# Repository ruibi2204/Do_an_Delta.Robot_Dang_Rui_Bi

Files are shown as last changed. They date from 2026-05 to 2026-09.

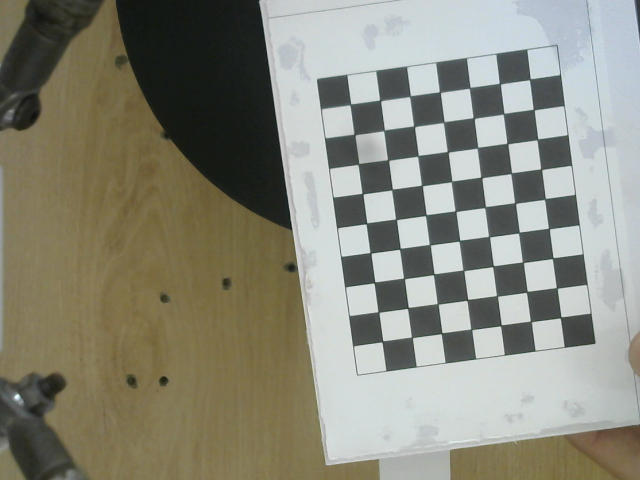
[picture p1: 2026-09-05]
Xử lý ảnh/Calibrarion_XY/images/calib_070.png

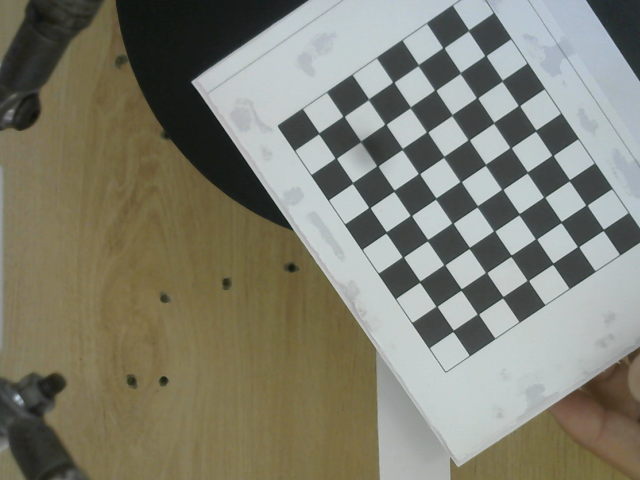
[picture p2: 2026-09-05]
Xử lý ảnh/Calibrarion_XY/images/calib_063.png

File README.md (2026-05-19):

ĐẶNG RUI BI_CƠ ĐIỆN TỬ
ĐỒ ÁN TỐT NGHIỆP: Thiết kế chế tạo robot song song delta phục vụ cho học tập và nghiên cứu
Chi tiết: + Xây dụng mô hình toán với cấu trúc song song
          + Xây dựng cấu trúc code chuẩn, logic
          + Tạo ra mô hình cơ khí hoàn chỉnh từ thiết kế đến gia công lắp ráp
          + Ứng dụng vào nhiều bài toán khác nhau mang tính đa dạng
          + Kết hợp thị giác máy tính làm đôi mắt cho các dạng bài toán xác định vật thể
          + Dùng bộ điều khiển PID giúp Robot di chuyển ổn định và hạ thấp sai số đến tối thiểu
Mã số SINH VIÊN: CNCD2211024
Trường Đại học Kỹ thuật - Công nghệ Cần Thơ

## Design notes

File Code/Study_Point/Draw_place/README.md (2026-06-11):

# Delta Robot Trajectory Controller

Phần mềm điều khiển quỹ đạo Robot Delta — Đồ án tốt nghiệp.

## Cấu trúc dự án

```
delta_robot/
├── main.py                          ← Chạy file này
├── kinematics/
│   ├── __init__.py
│   └── inverse_kinematics.py        ← Động học nghịch (Weierstrass)
├── trajectory/
│   ├── __init__.py
│   └── generator.py                 ← Sinh quỹ đạo tròn / vuông / tam giác
├── communication/
│   ├── __init__.py
│   └── uart_comm.py                 ← Giao tiếp Serial với stepper driver
└── gui/
    ├── __init__.py
    └── controller_gui.py            ← Giao diện Tkinter full-screen
```

## Thông số robot

| Tham số | Giá trị | Mô tả |
|---|---|---|
| R | 100 mm  | Bán kính mâm tĩnh |
| a | 130 mm  | Chiều dài cánh tay trên |
| b | 298 mm  | Chiều dài cánh tay dưới |
| r | 35.3 mm | Bán kính mâm động |
| u | 3.8 | Tỉ số truyền đai stepper |

## Cài đặt

```bash
pip install numpy pyserial
```

> `pyserial` là tùy chọn — nếu chưa cài, chương trình tự động dùng chế độ **DRY-RUN** (mô phỏng, không cần phần cứng).

## Chạy chương trình

```bash
cd delta_robot
python main.py
```

## Hướng dẫn sử dụng

1. **Chọn hình** (Tròn / Vuông / Tam giác) ở panel trái
2. **Nhập tham số** (bán kính, cạnh, tâm XY, độ cao Z)
3. **Kết nối Serial**: chọn cổng COM (hoặc để DRY-RUN để test)
4. Nhấn **▶ BẮT ĐẦU VẼ** — quan sát quỹ đạo trên canvas và góc khớp bên dưới
5. Nhấn **⌂ HOME** để đưa robot về vị trí gốc

## Định dạng UART

Mỗi bước gửi một dòng ASCII:

```
T1:<stepper1> T2:<stepper2> T3:<stepper3>\n
```

Trong đó `stepper_i = theta_i × 3.8` (tỉ số truyền đai).

**Ví dụ:**
```
T1:42.56 T2:-31.08 T3:38.95
HOME
```

## Mở rộng

- Thêm hình vẽ mới: tạo hàm trong `trajectory/generator.py` và thêm tab trong `gui/controller_gui.py`
- Thay đổi giao thức UART: chỉnh hàm `send_angles()` trong `communication/uart_comm.py`
- Thay đổi thông số robot: chỉnh hằng số trong `kinematics/inverse_kinematics.py`

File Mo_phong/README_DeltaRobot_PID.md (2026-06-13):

# ROBOT DELTA – BỘ ĐIỀU KHIỂN PID SIMULINK

## Cấu trúc file

| File | Chức năng |
|---|---|
| `delta_robot_pid.m` | Script chính: mô phỏng PID + tự tạo model Simulink |
| `build_delta_simulink.m` | Hàm riêng: chỉ tạo file `.slx` (dùng API Simulink) |

---

## Cách sử dụng

### Cách 1 – Chạy nhanh (không cần Simulink license)
```matlab
run('delta_robot_pid.m')
```
- Mô phỏng bằng vòng lặp MATLAB (RK4)
- Vẽ 9 đồ thị: góc, sai số, mô-men
- Tính RMSE từng khớp
- Tự động gọi `create_simulink_model()` để sinh file `.slx`

### Cách 2 – Chỉ tạo Simulink model
```matlab
build_delta_simulink()
```
Yêu cầu: **MATLAB R2019b+** có Simulink.

---

## Sơ đồ khối Simulink (mỗi khớp)

```
Ref_Ji ──┬──► [Sum] ──► [PID Controller] ──► [Plant 1/(Js+b)] ──► [Integrator] ──► θi
         │      ▲─────────────────────────────────────────────────────────────────────┘
         │    (phản hồi âm)
         └── [Scope / To Workspace]
```

**3 vòng điều khiển độc lập** – một vòng cho mỗi khớp (θ₁, θ₂, θ₃).

---

## Thông số mặc định

### Cơ học robot Delta
| Ký hiệu | Giá trị | Đơn vị |
|---|---|---|
| L1 (cánh tay trên) | 0.30 | m |
| L2 (cánh tay dưới) | 0.60 | m |
| r_base | 0.20 | m |
| r_platform | 0.05 | m |
| m (tải) | 0.50 | kg |
| J (quán tính khớp) | 0.01 | kg.m² |
| b (cản) | 0.05 | N.m.s/rad |

### Tham số PID (3 khớp giống nhau)
| Tham số | Giá trị |
|---|---|
| Kp | 120 |
| Ki | 15 |
| Kd | 8 |
| τ_max | ±30 N.m |
| Anti-windup | Clamping |

### Quỹ đạo tham chiếu (hình sin lệch pha 120°)
```
θ1_ref(t) = 0.5·sin(π·t)
θ2_ref(t) = 0.5·sin(π·t + 2π/3)
θ3_ref(t) = 0.5·sin(π·t + 4π/3)
```

---

## Điều chỉnh PID

Thay đổi giá trị trong phần **Section 2** của `delta_robot_pid.m`:
```matlab
pid.Kp1 = 120;   pid.Ki1 = 15;   pid.Kd1 = 8;
```

**Hướng dẫn chỉnh thô:**
- Tăng `Kp` → đáp ứng nhanh hơn, dễ vọt lố
- Tăng `Ki` → giảm sai số tĩnh, dễ dao động
- Tăng `Kd` → giảm vọt lố, tăng ổn định

---

## Yêu cầu
- MATLAB R2019b trở lên
- Simulink (để chạy `build_delta_simulink.m`)
- Control System Toolbox (tùy chọn)

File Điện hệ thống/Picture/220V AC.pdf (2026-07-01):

## 220 VAC

L | N | E_STOP

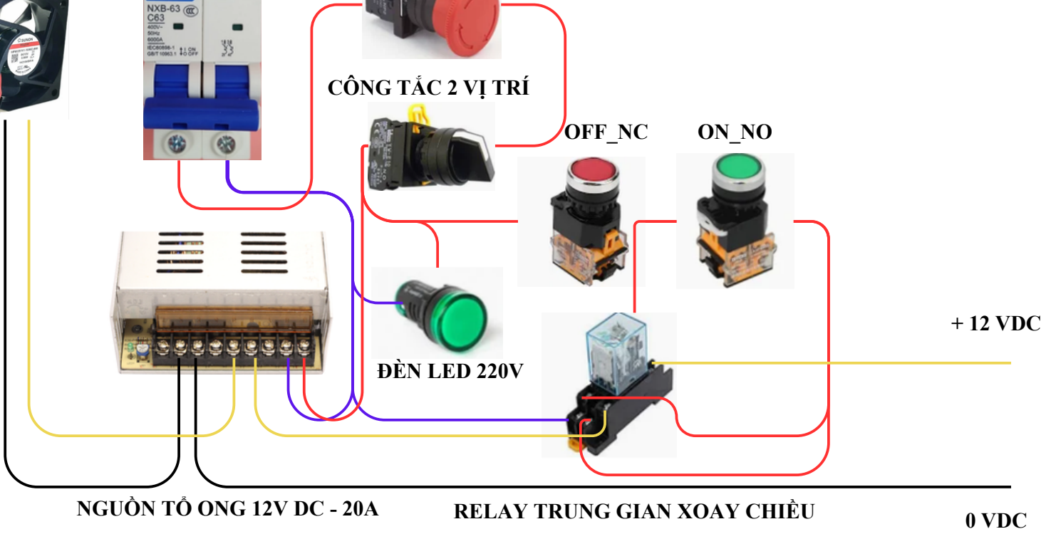
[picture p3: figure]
ĐÈN LED 220V; CÔNG TẮC 2 VỊ TRÍ; OFF_NC; + 12 VDC; 0 VDC

NGUỒN TỔ ONG 12V DC - 20A | RELAY TRUNG GIAN XOAY CHIỀU

QUẠT TẢN NHIỆT

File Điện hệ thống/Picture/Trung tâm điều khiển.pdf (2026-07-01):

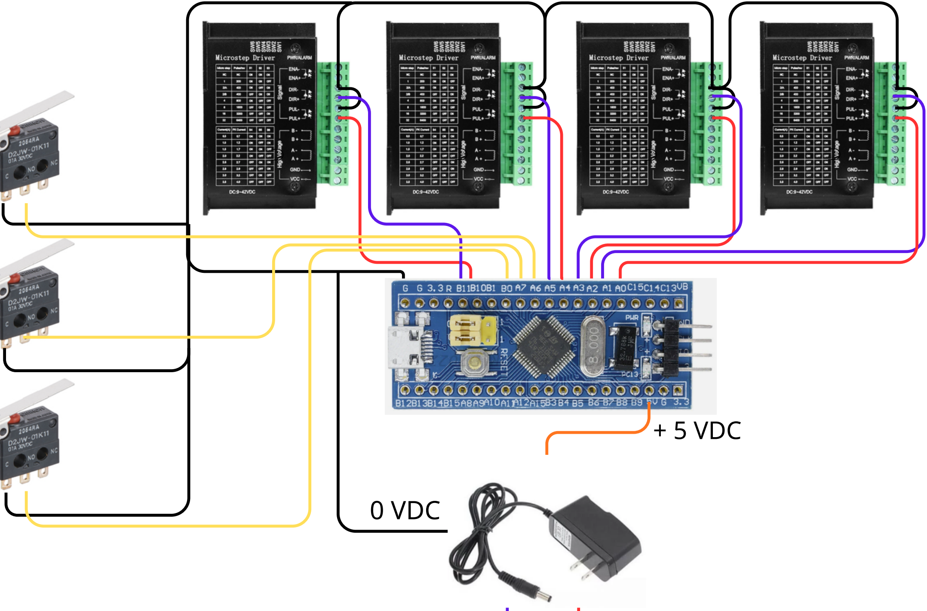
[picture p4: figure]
0 VDC; + 5 VDC

N L
220V AC

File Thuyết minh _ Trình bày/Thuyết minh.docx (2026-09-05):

TRƯỜNG ĐẠI HỌC KỸ THUẬT - CÔNG NGHỆ CẦN THƠ

KHOA KỸ THUẬT CƠ KHÍ

ĐỒ ÁN TỐT NGHIỆP

Đề tài:

THIẾT KẾ, CHẾ TẠO ROBOT SONG SONG DELTA

ỨNG DỤNG TRONG HỌC TẬP VÀ NGHIÊN CỨU

GIẢNG VIÊN HƯỚNG DẪN | SINH VIÊN THỰC HIỆN
Th.S. Trần Sĩ Lâm | Họ và tên: Đặng Rui Bi MSSV: CNCD2211024 Ngành: Công nghệ - Kỹ thuật Cơ Điện Tử

Cần thơ, tháng … năm 2026

TRƯỜNG ĐẠI HỌC KỸ THUẬT- CÔNG NGHỆ CẦN THƠ

KHOA KỸ THUẬT CƠ KHÍ

ĐỒ ÁN TỐT NGHIỆP

Đề tài:

THIẾT KẾ, CHẾ TẠO ROBOT SONG SONG DELTA

ỨNG DỤNG TRONG HỌC TẬP VÀ NGHIÊN CỨU

GIẢNG VIÊN HƯỚNG DẪN | SINH VIÊN THỰC HIỆN
Th.S. Trần Sĩ Lâm | Họ và tên: Đặng Rui Bi MSSV: CNCD2211024 Ngành: Công nghệ - Kỹ thuật Cơ Điện Tử

Cần thơ, tháng … năm 202

# LỜI CAM ĐOAN

Tôi tên là Đặng Rui Bi (mã số sinh viên: CNCD2211024), là sinh viên ngành Công nghệ - Kỹ thuật Cơ điện tử, khóa 2022. Tôi xin cam đoan đồ án này là công trình nghiên cứu khoa học thực sự của tôi và được sự hướng dẫn của ThS. Trần Sĩ Lâm.

Các thông tin được sử dụng tham khảo trong đề tài được thu thập từ các nguồn đáng tin cậy, đã được kiểm chứng, được công bố rộng rãi và được chúng tôi trích dẫn nguồn gốc rõ ràng ở danh mục Tài liệu tham khảo. Các kết quả nghiên cứu được trình bày trong đồ án này là do chính tôi thực hiện một cách nghiêm túc, trung thực và không trùng lặp với các đề tài khác đã được công bố trước đây.

Tôi xin lấy danh dự và uy tín của bản thân để đảm bảo cho lời cam đoan này.

Cần Thơ, ngày … tháng … năm 2026

Giảng viên hướng dẫn | Tác giả thực hiện
Trần Sĩ Lâm | Đặng Rui Bi

# LỜI CẢM ƠN

Lời đầu tiên, em xin gửi lời cảm ơn chân thành nhất đến các quý thầy cô Khoa Kỹ thuật Cơ khí – những người đã truyền đạt kiến thức, giúp đỡ và tạo điều kiện thuận lợi cho chúng em trong suốt quá trình học tập và rèn luyện tại trường.

Đặc biệt, em xin bày tỏ lòng biết ơn sâu sắc đến ThS. Trần Sĩ Lâm, giảng viên đã trực tiếp hướng dẫn và đồng hành cùng em xuyên suốt quá trình thực hiện đồ án này. Sự kiên nhẫn, tận tâm và những chỉ dẫn chuyên môn quý báu của Thầy là nguồn động lực lớn lao giúp em vượt qua những khó khăn, thách thức trong quá trình nghiên cứu kỹ thuật. Những kiến thức và kinh nghiệm thực tiễn mà Thầy chia sẻ không chỉ giúp nhóm hoàn thiện đồ án một cách tốt nhất mà còn giúp em nhìn nhận ra những thiếu sót để cải thiện và phát triển bản thân hơn nữa.

Dù đã dành nhiều tâm huyết và nỗ lực, nhưng do kiến thức còn hạn chế, đồ án chắc chắn không tránh khỏi những khiếm khuyết. Nhóm chúng em rất mong nhận được những ý kiến đóng góp của các thầy cô để đề tài được hoàn thiện hơn.

Một lần nữa, em xin chân thành cảm ơn Thầy!

Cần Thơ, ngày … tháng … năm 2026

Tác giả thực hiện

Đặng Rui Bi

# NHẬN XÉT CỦA GIẢNG VIÊN

# MỤC LỤC

# DANH MỤC HÌNH

# DANH MỤC BẢNG

# DANH MỤC TỪ VIẾT TẮT

# DANH MỤC KÝ HIỆU

# LỜI MỞ ĐẦU

Trong thời kỳ phát triển công nghiệp hiện nay, ngành công nghiệp robot đóng vai trò vô cùng quan trọng, trở thành động lực phát triển của nhiều lĩnh vực sản xuất, y tế, dịch vụ,… Robot không những giúp tự động hóa các quy trình, nâng cao năng suất mà còn giảm thiểu rủi ro cho con người trong các môi trường nguy hiểm.

Trong số các loại robot công nghiệp, robot song song nổi bật với những ưu điểm vượt trội về độ cứng vững cao, độ chính xác và tốc độ làm việc nhanh chóng. Đặc biệt, robot Delta, với cấu trúc động học song song độc đáo, đã chứng minh được hiệu quả vượt trội trong các ứng dụng đòi hỏi tốc độ cao như phân loại, đóng gói, lắp ráp linh kiện điện tử và phẫu thuật. Khả năng di chuyển nhanh và chính xác của robot Delta đã mở ra nhiều tiềm năng ứng dụng mới, góp phần nâng cao hiệu suất và tối ưu hóa quy trình sản xuất.

Với mong muốn tìm hiểu sâu hơn về lĩnh vực robot học nói chung và robot song song Delta nói riêng, cũng như ứng dụng những kiến thức đã học vào thực tiễn, tôi đã lựa chọn đề tài "Thiết kế, chế tạo robot song song Delta phục vụ cho học tập và nghiên cứu" làm đề tài báo cáo tốt nghiệp của mình. Đề tài này không chỉ giúp tôi củng cố kiến thức về động học, động lực học và điều khiển robot, mà còn trang bị những kỹ năng thực tế trong việc xây dựng và vận hành một hệ thống robot hoàn chỉnh.

Tuy nhiên, với phạm vi kiến thức còn hạn chế, trong quá trình thực hiện đề tài không tránh khỏi những thiếu sót và gặp phải nhiều thách thức. Tôi rất mong nhận được sự quan tâm, góp ý và hỗ trợ từ quý thầy cô để có thể hoàn thiện tốt đề tài này.

Em xin chân thành cảm ơn!

# TÓM TẮT

Trong thời đại tự động hóa trong công nghiệp ngày càng phát triển mạnh mẽ, các Robot tự hành trong các dây chuyền sản xuất ngày càng phổ biến trong đó có Robot song song Delta. Tôi quyết định thực hiện đề tài Thiết kế, chế tạo Robot song song Delta nhằm tạo ra mô hình Robot Delta hoàn chỉnh với mục tiêu tối ưu hóa khả năng điều khiển vị trí và quy hoạch quỹ đạo chính xác trong không gian ba chiều. Nội dung nghiên cứu bắt đầu từ việc thiết lập nền tảng lý thuyết thông qua mô hình toán học động học thuận và nghịch bằng phương pháp giải tích, giúp xác định chính xác không gian làm việc và làm cơ sở cho việc tính toán động lực học để lựa chọn hệ thống truyền động phù hợp. Song song đó, hệ thống cơ khí được thiết kế tối ưu với kết cấu nhẹ nhằm giảm thiểu quán tính, kết hợp cùng bộ điều khiển trung tâm được thiết lập linh động và giao diện giao tiếp trực tiếp trên laptop để giám sát vận hành thời gian thực. Đặc biệt, đề tài đi sâu vào việc tích hợp hệ thống thị giác máy tính hiện đại để nhận diện, phân loại vật thể theo màu sắc và hình dạng, đồng thời triển khai các thuật toán điều khiển giúp robot thực hiện mượt mà các quỹ đạo hình học phức tạp như hình tròn, hình vuông và hình tam giác. Kết quả cuối cùng hướng tới việc tạo ra một hệ thống Robot Delta hoàn chỉnh, vận hành ổn định và có tính tùy biến cao, đóng vai trò như một học cụ nghiên cứu thực thụ.

# CHƯƠNG 1 TỔNG QUAN VỀ ĐỀ TÀI

# 1.1 Giới thiệu về Robot công nghiệp

Robot công nghiệp thường được đề cập trong bối cảnh các đổi mới công nghệ của thế kỷ 21. Tuy nhiên, nguồn gốc của chúng đã xuất hiện từ rất sớm - vào những năm 1950.

Hình 1.1 Robot "Unimate" – robot công nghiệp đầu tiên trên dây chuyền lắp ráp ô tô

Robot công nghiệp lần đầu tiên được thương mại hóa vào đầu thập niên 1960, chủ yếu phục vụ trong các dây chuyền lắp ráp ô tô. Những thiết bị đầu tiên được thiết kế với cánh tay thủy lực hoặc khí nén, chủ yếu để nâng vật nặng và hỗ trợ các công việc nguy hiểm. Đến giữa những năm 1980, robot được nhìn nhận là “cỗ máy của tương lai”. Đây là giai đoạn quan trọng, đánh dấu sự chuyển đổi từ máy cơ học sang robot có khả năng cảm nhận. Robot bắt đầu được tích hợp cảm biến lực, cảm biến vị trí, thị giác máy (machine vision) dù còn sơ khai nhưng đã mở ra hướng phát triển mới cho khả năng tương tác với môi trường.

Bên cạnh đó, sự phát triển của phần cứng máy tính, đặc biệt là việc giảm giá thành bộ vi xử lý, đã cho phép các robot được điều khiển linh hoạt hơn, thông minh hơn và phù hợp với nhiều quy trình sản xuất khác nhau. Trong bối cảnh đó, các loại robot có cấu trúc đặc biệt như robot song song delta cũng bắt đầu được chú ý nhờ khả năng hoạt động cực nhanh và chính xác, phù hợp với các nhiệm vụ như phân loại sản phẩm trên băng chuyền.

Hiện nay, Robot được coi là một phần không thể thiếu trong công nghiệp, tồn tại với qui mô vượt trội và ngày càng thông minh. Có rất nhiều loại Robot ngày càng được cải tiến mạnh mẽ cùng với đó là khả năng xử lý vượt trội, phổ biến có thể kể đến như:

- Robot nối tiếp:

Robot nối tiếp là một hệ động học hở bao gồm nhiều khâu nối tiếp với nhau thông qua các khớp, thường là khớp tịnh tiến hoặc khớp xoay. Các khớp cho phép các khâu chuyển động tương đối với nhau, từ đó robot có thể thực hiện nhiều tác vụ từ việc điều khiển cơ cấu tác động di chuyển trong không gian.

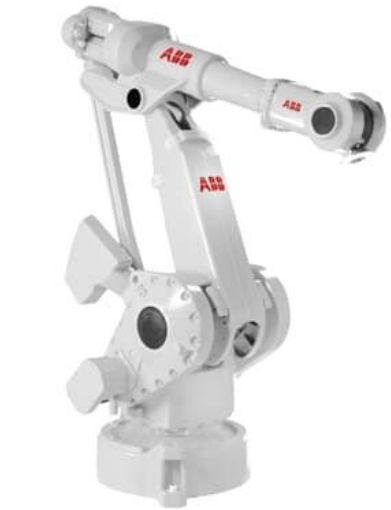
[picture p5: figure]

Với kết cấu nối tiếp, robot có vùng không gian làm việc lớn hơn so với kích thước của nó. Nhờ đó robot nối tiếp được ứng dụng nhiều trong sản xuất ô tô, sắp xếp các pallet, sơn phủ, hàn, cắt vật liệu và nhiều ngành khác. Tuy vậy robot nối tiếp cũng có một số nhược điểm như robot nối tiếp thường có khối lượng lớn nên quán tính lớn do đó robot bị giới hạn về mặt tốc độ chuyển động, tốc độ làm việc chưa cao.

Hình 1.2 Cánh tay Robot nối tiếp của tập đoàn ABB

- Robot song song:

Khác với robot nối tiếp, robot song song là là một hệ cơ cấu động học kín. Bộ phận công tác của robot được kết nối với khâu cố định thông qua chuỗi các khâu riêng biệt, trong đó bao gồm một khâu chủ động liên kết với khâu đế và khâu bị động liên kết với đầu công tác như hình 1.3. Chuyển động của bộ phận công tác được điều khiển thông qua việc điều khiển các chuỗi liên kết một cách phối hợp.

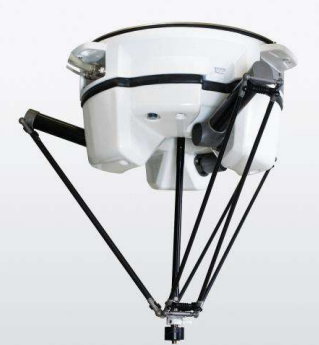
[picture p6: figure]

Hình 1.3 Robot IRB 360 - 3/1130 của tập đoàn ABB

Mặc dù robot song song có cấu trúc động học phức tạp, không gian làm việc nhỏ, khó thiết kế và điều khiển, nhưng nó có một số ưu điểm nổi trội so với robot nối tiếp. Các robot song song thường có khối lượng nhẹ nên có khả năng di chuyển với tốc độ cao, bên cạnh đó kết cấu song song giúp robot không bị tích lũy sai số như robot nối tiếp do các chuỗi liên kết ràng buộc lẫn nhau. Robot song song thường được sử dụng trong các ứng dụng có độ chính xác và tốc độ cao như ngành sản xuất, hàng không vũ trụ và y tế.

# 1.2 Giới thiệu Robot song song Delta

Robot Delta là một loại robot song song được phát minh bởi giáo sư Reymond Clavel và các cộng sự của ông vào năm 1986. Giống như các robot song song khác, robot Delta cũng có cấu trúc vòng kín được thể hiện ở hình 1.4. Trong đó có ba chuỗi động học độc lập, mỗi chuỗi gồm một đầu gắn với khâu giá cố định, đầu kia gắn với khâu công tác thông qua cơ cấu hình bình hành. Chuyển động của khâu công tác được điều khiển nhờ ba động cơ gắn trên giá cố định. Với cơ cấu đó, khâu công tác chỉ có thể chuyển động tịnh tiến theo các phương X, Y, Z trong không gian mà không xoay theo các phương này.

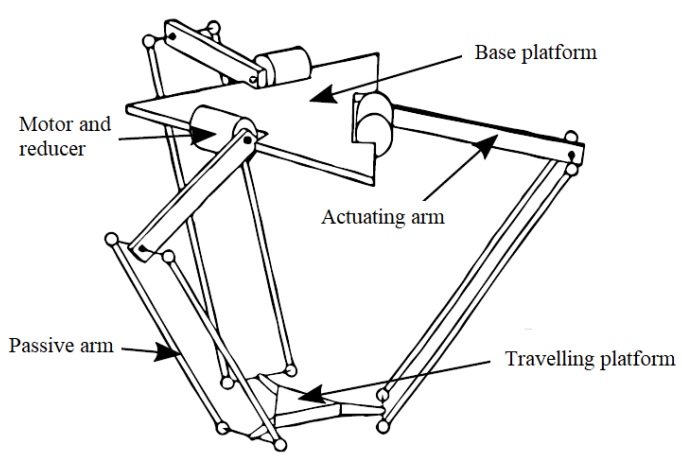
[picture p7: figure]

Hình 1.4 Kết cấu Delta Robot

Vì các bộ truyền động thường được đặt cố định trên khâu giá nên các khâu còn lại của robot thường được làm bằng các vật liệu rất nhẹ. Do đó, robot Delta thường có quán tính nhỏ, vì thế mà chúng có thể hoạt động ở tốc độ cao và có khả năng tăng tốc nhanh. Với những ưu điểm trên, robot Delta rất thích hợp để ứng dụng trong định vị và định hướng các sản phẩm trong các dây chuyền công nghiệp.

Đặc điểm nổi bật của Robot Delta:

- Tốc độ cực cao: Đây là ưu điểm nổi bật nhất của robot Delta. Do các động cơ được đặt cố định trên bệ tĩnh và chỉ các khâu nhẹ di chuyển, robot có thể đạt được gia tốc và tốc độ rất lớn, lên đến hàng trăm lần chọn và đặt mỗi phút.
- Độ chính xác và lặp lại cao: Cấu trúc song song giúp phân bố lực đều, giảm thiểu sai số tích lũy và độ võng, mang lại độ chính xác vị trí và độ lặp lại vượt trội (thường dưới 0.1mm).
- Vùng làm việc hình bán cầu: Vùng làm việc của robot Delta thường có hình dạng bán cầu hoặc tương tự, phù hợp cho các nhiệm vụ trong không gian giới hạn phía dưới nó.
- Chỉ có khả năng tịnh tiến (X, Y, Z) cơ bản: Robot Delta nguyên bản chỉ thực hiện được 3 bậc tự do tịnh tiến. Để có thêm khả năng quay (orientation), cần bổ sung thêm các khớp phụ hoặc cấu trúc phức tạp hơn (ví dụ: Delta 4 bậc tự do với trục quay ở cuối).
- Động học ngược đơn giản, động học thuận phức tạp: Việc tính toán động học ngược (từ vị trí mong muốn của bệ động để tìm ra góc quay của các động cơ) thường đơn giản và có thể giải được bằng phương pháp giải tích. Ngược lại, động học thuận (từ góc quay 10 của các động cơ để tìm ra vị trí của bệ động) thường phức tạp hơn và có thể cần giải bằng phương pháp số.
- Thiết kế vệ sinh (Hygienic Design): Do các động cơ và phần lớn cơ cấu truyền động nằm phía trên bệ tĩnh, robot Delta dễ dàng được thiết kế để đáp ứng các tiêu chuẩn vệ sinh nghiêm ngặt, lý tưởng cho ngành thực phẩm và dược phẩm.

# 1.3 Ứng dụng của Robot Delta

# 1.3.1 Trong lĩnh vực công nghệ cao, tự động hóa

Ứng dụng: Robot Delta là lựa chọn hàng đầu cho các ngành công nghiệp đòi hỏi tốc độ và độ chính xác cao trong việc xử lý các vật thể nhỏ và nhẹ:

- Phân loại và đóng gói: Trong ngành thực phẩm (kẹo, bánh quy), dược phẩm (viên thuốc), điện tử (linh kiện nhỏ).
- Lắp ráp linh kiện điện tử: Lắp ráp các chi tiết nhỏ, ví dụ như chip lên bảng mạch.
- Chọn và đặt (Pick-and-place): Di chuyển nhanh các vật thể từ vị trí này sang vị trí khác trên dây chuyền sản xuất.
- Kiểm tra sản phẩm: Di chuyển cảm biến hoặc camera để kiểm tra sản phẩm trên dây chuyền với tốc độ cao.
- Ứng dụng y tế: Một số biến thể được dùng trong phẫu thuật hoặc các thiết bị y tế đòi hỏi độ chính xác cao.

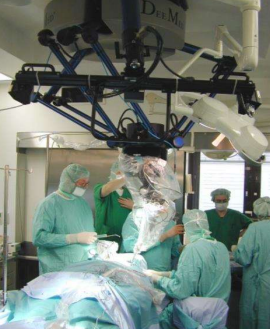
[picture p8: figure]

Hình 1.5 Ứng dụng Delta Robot trong đóng gói sản phẩm

Hình 1.6 Mang kính hiển vi phẫu thuật

# 1.3.2 Trong lĩnh vực học tập và nghiên cứu

Robot Delta là một đối tượng nghiên cứu điển hình trong lĩnh vực cơ học nhờ cấu trúc động học song song (parallel kinematics) độc đáo. Khác với các robot dạng chuỗi hở thông thường, Robot Delta sử dụng ba cánh tay cơ học được nối từ một đế cố định đến một mâm chuyển động (end-effector). Trong nghiên cứu, việc phân tích bài toán động học thuận và nghịch của Delta đòi hỏi các mô hình toán học phức tạp để xác định vị trí chính xác của mâm động dựa trên góc quay của các động cơ servo, stepper. Các nhà nghiên cứu thường tập trung vào việc tối ưu hóa "vùng làm việc" (workspace) và phân tích các điểm kỳ dị (singularities) để đảm bảo robot vận hành ổn định. Nhờ cấu tạo nhẹ và độ cứng vững cao, đây là mô hình lý tưởng để thử nghiệm các thiết kế cơ khí chính xác, nơi mà sai số tích lũy từ các khớp nối được giảm thiểu tối đa so với robot truyền thống.

Trong môi trường học thuật, robot Delta đóng vai trò là nền tảng quan trọng để triển khai và kiểm chứng các thuật toán điều khiển tốc độ cao. Do đặc thù được thiết kế cho các tác vụ "Pick and Place" (gắp và đặt), việc lập trình quỹ đạo (trajectory planning) cho Delta yêu cầu khả năng xử lý thời gian thực cực kỳ nhạy bén để đạt được gia tốc lớn mà không gây rung lắc. Sinh viên và nghiên cứu sinh thường ứng dụng các bộ điều khiển PID nâng cao, điều khiển mờ (Fuzzy Logic) hoặc mạng nơ-ron để tối ưu hóa chuyển động. Bên cạnh đó, việc tích hợp hệ thống thị giác máy tính (Computer Vision) vào robot Delta là một hướng nghiên cứu phổ biến, cho phép robot nhận diện, phân loại và bám sát đối tượng trong không gian ba chiều với độ trễ thấp. Đây chính là bước đệm quan trọng để phát triển các hệ thống sản xuất thông minh và tự động hóa linh hoạt trong tương lai.

# 1.3.3 Xét trên phạm vi Trường Đại học Kỹ thuật – Công nghệ Cần Thơ

Tại Trường Đại học Kỹ thuật – Công nghệ Cần Thơ, robot Delta không còn là một khái niệm quá xa lạ khi đã có những công trình nghiên cứu và sản phẩm thực nghiệm từ các thế hệ sinh viên đi trước. Tuy nhiên, phần lớn các nghiên cứu này thường tập trung vào những mục tiêu chuyên biệt, khiến việc tiếp cận hệ thống dưới dạng một nền tảng mở cho nhiều bài toán khác nhau vẫn còn gặp nhiều hạn chế, số bậc tự do là 3 bậc. Đây chính là động lực cốt lõi để tôi thực hiện đồ án này, với mong muốn xây dựng một mô hình robot Delta có tính linh hoạt cao và khả năng tùy biến linh hoạt hơn. Thay vì chỉ dừng lại ở một ứng dụng đơn lẻ, mục tiêu của tôi là tạo ra một cấu trúc có tính kế thừa, giúp các sinh viên khóa sau dễ dàng tiếp cận, thực hiện các bài toán từ điều khiển quỹ đạo phức tạp đến tích hợp thị giác máy tính. Việc tối ưu hóa cấu hình thiết bị không chỉ nhằm mục đích hoàn thành một đồ án tốt nghiệp, mà còn hướng đến việc xây dựng một học cụ nghiên cứu thực thụ, góp phần mở rộng không gian sáng tạo và ứng dụng công nghệ robot song song tại chính ngôi trường mình đang theo học.

# 1.4 Mục tiêu đặt ra và mục đích chính của đề tài

# 1.4.1 Mục tiêu

Với thực trạng cách thức điều khiển tại Trường Đại học Kỹ thuật - Công nghệ Cần Thơ còn khá đơn điệu, tôi quyết định xây dựng đề tài này với các mục tiêu cấp thiết như sau:

- Vận dụng các kiến thức đã tích góp trong suốt quá trình học tập tại trường.
- Xây dựng được mô hình toán, phân tích động học bao gồm thuận và nghịch của Robot.
- Chế tạo mô hình Robot Delta 4 bậc tự do.
- Tạo ra được mô hình hoàn thiện được kết hợp đầy đủ các kiến thức từ xử lý ảnh, thiết kế, mô phỏng đến lắp ráp cơ khí hoàn chỉnh.
- Thiết lập thuật toán và môi trường điều khiển linh động với các yêu cầu điều khiển khác nhau.
- Tạo được giao diện điều khiển trực tiếp trên laptop, dễ dàng trong việc tiếp cận và sử dụng.

# 1.4.2 Mục đích

Với những mục tiêu đã đặt ra, mục đích cuối cùng sẽ là tạo ra một Delta Robot 4 bậc tự do hoàn chỉnh, hệ thống điều khiển mở với các dạng bài cơ bản nhằm phục vụ cho việc học tập và nghiên cứu.

# 1.5 Phương pháp nghiên cứu

# 1.5.1 Phương pháp nghiên cứu lý thuyết

Phương pháp nghiên cứu lý thuyết tập trung vào việc thu thập tài liệu khoa học về cấu trúc robot song song để thiết lập mô hình toán học giải quyết bài toán động học thuận và nghịch. Từ đó, tiến hành tính toán động lực học nhằm phân tích lực, mô-men và lựa chọn các linh kiện phần cứng như động cơ bước phù hợp với yêu cầu tải trọng. Đồng thời, nghiên cứu thuật toán điều khiển và quy hoạch quỹ đạo trên không gian 3D được thực hiện để làm cơ sở thiết lập hệ thống vận hành chính xác. Cuối cùng, kết quả lý thuyết được kiểm chứng thông qua các mô phỏng trên phần mềm chuyên dụng trước khi triển khai chế tạo mô hình thực tế.

# 1.5.2 Phương pháp thực nghiệm

Phương pháp thực nghiệm được triển khai thông qua việc chế tạo mô hình vật lý dựa trên các thông số kỹ thuật đã tính toán, kết hợp lắp đặt hệ thống truyền động và cảm biến để kiểm chứng lý thuyết. Quá trình thực hiện bao gồm việc lập trình điều khiển trên máy tính và vi điều khiển, sau đó tiến hành chạy thử nghiệm để thu thập dữ liệu về độ sai số, tốc độ và khả năng đáp ứng của các cánh tay robot. Dựa trên kết quả đo đạc thực tế, các thông số bộ điều khiển và quỹ đạo chuyển động sẽ được tinh chỉnh trực tiếp nhằm tối ưu hóa độ chính xác và tính ổn định của hệ thống trong điều kiện vận hành thực. Cuối cùng, các dữ liệu thực nghiệm được so sánh với mô hình mô phỏng để đánh giá hoàn thiện thiết kế và đưa ra kết luận về khả năng ứng dụng của robot.

# 1.6 Phạm vi nghiên cứu

Phạm vi nghiên cứu của đề tài tập trung vào việc thiết kế và điều khiển mô hình robot Delta để thực hiện các nhiệm vụ đòi hỏi độ chính xác cao trong không gian ba chiều. Cụ thể, nghiên cứu giới hạn trong việc xây dựng thuật toán quy hoạch quỹ đạo để điều khiển robot thực hiện các đường nét hình học cơ bản như hình tròn, hình vuông và hình tam giác với sai số tối thiểu. Bên cạnh đó, đề tài đi sâu vào việc tích hợp hệ thống xử lý ảnh để nhận diện và phân loại vật thể dựa trên đặc trưng màu sắc và hình dạng, từ đó tối ưu hóa khả năng tương tác của robot trong các ứng dụng phân loại tự động. Các thử nghiệm và đánh giá được thực hiện trong môi trường phòng thí nghiệm nhằm kiểm chứng sự ổn định của hệ thống điều khiển và độ chính xác của các thuật toán động học đã thiết lập

# 1.7 Nội dung xây dựng đồ án

- CHƯƠNG 1 TỔNG QUAN:
- Giới thiệu về Robot công nghiệp nói chung và Robot Delta nói riêng.
- Nêu lên các ứng dụng cũng như tầm quan trọng của Robot Delta trong nhiều lĩnh vực từ đó tiến hành thực hiện đề tài.
- CHƯƠNG 2 XÂY DỰNG MÔ HÌNH CƠ HỌC VÀ MÔ HÌNH TOÁN HỌC CHO ROBOT SONG SONG DELTA:
- Xác định cấu trúc Robot gồm các khâu, khớp, số bậc tự do của Robot.
- Xây dựng nên các bài toán động học dùng phương pháp giải tích, hình học.
- Xét được phạm vi hoạt động lý thuyết cho Robot.
- CHƯƠNG 3 XỬ LÝ ẢNH:
- Tập trung nghiên cứu lý thuyết về xử lý ảnh. Xử dụng các phương pháp xử lý để đưa vào thực tiễn thông qua lập trình.
- CHƯƠNG 4 THIẾT KẾ HỆ THỐNG CƠ KHÍ VÀ HỆ THỐNG ĐIỀU KHIỂN ROBOT:
- Khái quát nguyên lý hoạt động của hệ thống.
- Tiến hành thiết kế cơ khí dựa vào thông số đã tính toán.
- Xây dựng khối điều khiển trung tâm, thiết lập bộ điều khiển và chọn linh kiện phù hợp.
- Tạo giao diện điều khiển để có thể giao tiếp với Robot.
- CHƯƠNG 5 ỨNG DỤNG VÀO CÁC YÊU CẦU ĐIỀU KHIỂN THỰC TẾ VÀ THU THẬP KẾT QUẢ :
- Đưa hệ thống vào các ứng dụng riêng sau đó thu thập kết quả.
- Đánh giá kết quả vừa thu thập được.
- CHƯƠNG 6 KẾT LUẬN TỔNG QUÁT VÀ HƯỚNG PHÁT TRIỂN ĐỀ TÀI TRONG TƯƠNG LAI:
- Đưa ra kết luận tổng quát về đề tài
- Đề ra hướng phát triển trong tương lai.
- TÀI LIỆU THAM KHẢO
- PHỤ LỤC

# CHƯƠNG 2 MÔ HÌNH HÓA HỆ THỐNG CƠ KHÍ

# 2.1 Cấu trúc Robot Delta

Hình 2.1 Thành phần và cấu trúc của Delta Robot

Hình 2.1 thể hiện cơ cấu của robot Delta với các thành phần cơ bản như sau:

- Khâu đế: là khâu cố định, chứa động cơ và là nơi gá đặt robot vào vị trí làm việc.
- Bộ truyền động bên ngoài: có chức năng truyền động từ motor trên khâu đế đến khâu khâu dẫn ứng với tỉ số truyền u.
- Khâu dẫn: gắn với bộ truyền đai rồi nối vào các động cơ ở khâu đế, có nhiệm vụ nhận lực từ động cơ và truyền đến khâu bị động.
- Khâu bị động: kết nối và truyền lực từ khâu dẫn tới khâu công tác.
- Khâu công tác: kết nối các khâu bị động ở các chuỗi truyền động với nhau, khâu công tác mang thêm đầu công tác và động cơ có trục quay theo trục Oz của robot để thực hiện tác vụ.

Ta xác định bậc tự do cho robot dựa vào công thức Somov-Malyshev cho cơ cấu không gian:

(2.1)

W=6n-∑_(i=1)^5 i.p_i

Trong đó:

- n là số khâu động của Robot.
- p_i là số khớp loại i hoặc bậc thứ i (i = 1, 2, 3, 4, 5). Trong Robot Delta, do kết cấu cơ khí mà ta chỉ xét p_5 cho phép 1 chuyển động và p_3 cho phép 3 chuyển động quay⁽*⁾.
- Từ Hình 2.1, ta tiến hành tính toán thông số như sau:

Xét số khâu (n) của Robot thì:

- 3 khâu dẫn (nối với motor ở base).
- 6 thanh truyền (tạo thành 3 cặp hình bình hành).
- 1 bàn tay máy (End-effector).
- 2 đoạn của trục giữa telescopic (lồng vào nhau).
- Tổng cộng: n = 3 + 6 + 1 + 2 = 12 khâu động.

Xét số khớp ( p_i ) của Robot thì:

- Khớp loại 5 ( p_5 - hạn chế 5 bậc tự do, cho phép 1 chuyển động) gồm 3 khớp quay tại 3 motor chính, 1 khớp quay của trục giữa nối với base, 1 khớp trượt giữa 2 đoạn của trục telescopic, 1 khớp quay của trục giữa nối với bàn tay máy.
- Khớp loại 3 ( p_3 - khớp cầu, cho phép 3 chuyển động quay) có 4 khớp/nhánh (3 nhánh)

Xét công thức (2.1) kết hợp với điều kiện ⁽*⁾ với ta thu được công thức chi tiết:

(2.2)

W=6n-(5p_5 +3p_3 )

- Thay các thông số vào công thức (2.2), ta tính được số bậc tự do như sau:

W=6.12-(5.6+3.4.3)=6

Mà Tại khâu bị động, robot dùng cơ cấu hình bình hành gồm 2 thanh thẳng kết nối 4 khớp cầu bậc 3 (2 khớp nối khâu chủ động và 2 khớp nối khâu công tác). Tuy nhiên, 2 thanh liên kết này bị khóa lại không thể xoay quanh trục của chính nó. Do đó tại mỗi khâu bị động thừa 2 bậc tự do. Suy ra:

W=6-2=4 (dof)

# 2.2 Kích thước của Robot Delta

Robot Delta gồm 3 chuỗi động học song song giống nhau, do đó kích thước của một chuỗi động học có thể biểu diễn được toàn bộ kích thước của robot. Hình 2.2 biểu diễn sơ đồ kích thước của chuỗi động học thứ i (i=1, 2, 3).

Điểm O là tâm khâu đế; điểm P là tâm khâu công tác.

Trong chuỗi động học thứ i gọi: Ai là tâm xoay của khâu dẫn; Bi là điểm nối giữa khâu dẫn và khâu bị động, Ci là điểm nối giữa khâu bị động và khâu công tác.

Hình 2.2 Sơ đồ kích thước chuỗi động học của robot Delta

- OA_i là vec-tơ từ tâm khâu đế đến tâm quay của khâu dẫn. OA_i = R = 122 mm
- A_i B_i là vec-tơ của khâu dẫn. A_i B_i = a = 130 mm
- B_i C_i là vec-tơ khâu bị động. B_i C_i = b = 298 mm
- C_i P_i là vec-tơ từ khâu bị động đến tâm khâu công tác. C_i P_i = r = 40 mm

# 2.3 Phân tích động học Robot Delta

Phân tích động học là một bước then chốt và bắt buộc trong quá trình thiết kế, điều khiển hệ thống Robot Delta. Mục tiêu cốt lõi của quá trình này là thiết lập mối quan hệ toán học giữa các thông số hình học của robot (chiều dài các khâu, bán kính đế) và trạng thái chuyển động của nó.

Xét gốc tọa độ và chiều dương như hình 2.3 có O(0; 0; 0). Ở đây, ta tính toán mà bỏ qua bước tìm bộ truyền đai và hãy xem như khâu dẫn được nối trực tiếp vào motor để dễ dàng tính toán.

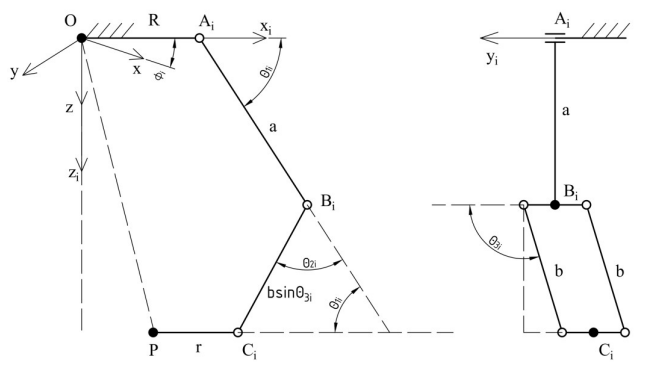
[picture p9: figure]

Hình 2.3 Sơ đồ nguyên lý một chuỗi động học của robot Delta

Sơ đồ nguyên lý trên cho thấy một chuỗi động học xét trên 1 nhánh bất kỳ thứ i bao gồm:

- O là tâm mặt phẳng khâu đế.
- Ai là tâm quay của khâu dẫn i ở cánh tay thứ i.
- Ci là điểm nối giữa khâu bị động và khâu công tác ở cánh tay thứ i.
- P là tâm của khâu công tác.

Thành lập 2 hệ tọa độ: Oxyz tại tâm O và Oxiyizi có trục Oxi trùng với chiều của vec-tơ OAi , φ là góc giữa trục Ox và trục Oxi. Như vậy, tương ứng với 3 cánh tay thì sẽ có 3 góc φ, (φ1 = 0°, φ2 = 120°, φ3 = 240°).

Quan hệ giữa các vec-tơ tương ứng với các khâu trên cánh tay thứ i được xét trên hệ tọa độ Oxiyizi:

(2.3)

OP+PC_i =OA_i +A_i B_i +B_i C_i

Khai triển công thức (2.3) bằng phương pháp tính toán tọa độ vec-tơ, ta thu được phương trình:

[P_(xi) P_(yi) P_(zi) ]+[r00]=[R00]+[acosθ_(1i) 0asinθ_(1i) ]+[bsinθ_(3i) cos(θ_(1i) +θ_(2i) )bcosθ_(3i) bsinθ_(3i) sin(θ_(1i) +θ_(2i) )]

- Áp dụng ma trận biến đổi theo góc quay _i để chuyển Oxiyizi về Oxyz như sau:

(2.5)

(2.4)

[P_(xi) P_(yi) P_(zi) ]=[cos_i , -sin_i , 0sin_i , cos_i , 00, 0, 1][P_x P_y P_z ]

- Mà A_i B_i +B_i C_i =A_i C_i , thế nên, ta có thể viết gọn lại:

(2.6)

[acosθ_(1i) +bsinθ_(3i) cos(θ_(1i) +θ_(2i) )bcosθ_(3i) asinθ_(1i) +bsinθ_(3i) sin(θ_(1i) +θ_(2i) )]=[C_(xi) C_(yi) C_(zi) ]

- Kết hợp công thức (2.3), (2.4), (2.5) và (2.6), ta thu được phương trình:

(2.7)

[C_(xi) C_(yi) C_(zi) ]=[cos_i , -sin_i , 0sin_i , cos_i , 00, 0, 1][P_x P_y P_z ]+[r-R00]

# 2.4 Bài toán động học nghịch

Nhiệm vụ của bài toán động học ngược là tìm ra các giá trị góc quay của ba khớp chủ động ( θ_11 , θ_12 , θ_13 ) khi biết tọa độ điểm công tác P ( P_x , P_y , P_z ). Từ quan hệ hình học (hình 2.3), suy ra:

(2.8)

cosθ_(3i) =(C_(yi))/b

Từ hang 1 và hàng 3 của ma trận (2.6), ta thu được hệ phương trình như sau:

(2.9)

{, C_(xi) =acosθ_(1i) +bsinθ_(3i) cos(θ_(1i) +θ_(2i) ), C_(zi) =asinθ_(1i) +bsinθ_(3i) sin(θ_(1i) +θ_(2i) )

Giải hệ phương trình (2.9), suy ra:

(2.10)

2a(C_(xi) cosθ_(1i) +C_(zi) sinθ_(1i) )=C_(xi) ^2 +C_(zi) ^2 +a^2 -b^2 (sinθ_(3i) )^2

Biến đổi phương trình (2.10) bằng phương pháp sử dụng phép thế Weierstrass với t=tan(θ_(1i))/2 , suy ra:

2a(C_(xi) .(1-t^2)/(1+t^2)+C_(zi) .(2t)/(1+t^2))=C_(xi) ^2 +C_(zi) ^2 +a^2 -b^2 (sinθ_(3i) )^2

Giải phương trình (2.11), ta suy ra được góc θ_(1i) theo công thức:

(2.12)

(2.11)

θ_(1i) =2tan^(-1) (t)

Biểu thức (2.12) cho ra 2 giá trị góc θ_(1i) . Vậy mỗi chuỗi động học sẽ có 2 giá trị góc θ_(1i) , tổ hợp lại thu được 8 bộ giá trị ( θ_11 , θ_12 , θ_13 ). Kiểm tra kết quả trên bằng thông số đầu vào là điểm công tác P có tọa độ bất kỳ trong phạm vi. Hình 2.4 biểu diễn 8 cấu hình robot ứng với 8 bộ giá trị ( θ_11 , θ_12 , θ_13 ).

Hình 2.4 Sơ đồ kích thước chuỗi động học của robot Delta

Tuy nhiên trong thực tế, chỉ có duy nhất bộ giá trị ( θ_11 , θ_12 , θ_13 ) < 90 o ứng với tổhợp [(-)(-)(-)] là được sử dụng do giới hạn về kết cấu cơ khí của robot.

# 2.5 Bài toán động học thuận

Bài toán động học thuận yêu cầu tìm ra tọa độ điểm công tác P ( P_x , P_y , P_z ) khi biết được giá trị góc quay ( θ_11 , θ_12 , θ_13 ) của các khớp chủ động tại 3 motor. Từ mỗi góc quay θ_(1i) cho trước, tìm mặt cầu s_i tạo bởi tất cả các điểm P có thể tìm được bởi cánh tay thứ i. Với 3 cánh tay cho ra 3 mặt cầu. Giao điểm của 3 mặt cầu trên chính là vị trí điểm P cần tìm.

Phương trình (2.3) được viết lại như sau:

(2.13)

OP+PC_i +A_i O+B_i A_i =B_i C_i

Từ phương trình (2.13) suy ra:

(2.14)

[P_(xi) P_(yi) P_(zi) ]+[r00]-[R00]-[acosθ_(1i) 0asinθ_(1i) ]=[bsinθ_(3i) cos(θ_(1i) +θ_(2i) )bcosθ_(3i) bsinθ_(3i) sin(θ_(1i) +θ_(2i) )]

Kết hợp phương trình (2.5) với (2.14), phương trình (2.15) sẽ là:

[cos_i , -sin_i , 0sin_i , cos_i , 00, 0, 1][P_x P_y P_z ]+[r00]-[R00]-[acosθ_(1i) 0asinθ_(1i) ]=[bsinθ_(3i) cos(θ_(1i) +θ_(2i) )bcosθ_(3i) bsinθ_(3i) sin(θ_(1i) +θ_(2i) )]

Biến đổi phương trình (2.15), ta thu được phương trình (2.16):

[P_x cos_i -sin_i P_y P_y cos_i +sin_i P_x P_z ]+[r-R-acosθ_(1i) 0-asinθ_(1i) ]=[bsinθ_(3i) cos(θ_(1i) +θ_(2i) )bcosθ_(3i) bsinθ_(3i) sin(θ_(1i) +θ_(2i) )]

Để dễ dàng tìm mặt cầu s_i , ta giải phương trình (2.16):

(2.17)

[P_x cos_i -sin_i P_y +r-R-acosθ_(1i) P_y cos_i +sin_i P_x P_z -asinθ_(1i) ]=[bsinθ_(3i) cos(θ_(1i) +θ_(2i) )bcosθ_(3i) bsinθ_(3i) sin(θ_(1i) +θ_(2i) )]

Sau khi tính toán và biến đổi phương trình (2.17), phương trình mặt cầu s_i (mặt cầu tâm C_i bán kính b) tại nhánh thứ i bằng cách modul hóa 2 vế:

b^2 = P_x ^2 +P_y ^2 +P_z ^2 +2(P_x cos_i -sin_i P_y )(r-R-acosθ_(1i) )

(2.18)

+ (r-R-acosθ_(1i) )^2 -2P_z asinθ_(1i) +(asinθ_(1i) )^2

Dựa trên cấu trúc phương trình (2.18), thực hiện phép trừ giữa hai nhánh i và j, phương trình mặt phẳng chứa giao điểm của 3 mặt cầu (đường thẳng giao tuyến nhìn từ hình chiếu) có dạng tổng quát:

(2.19)

[2cos_i (r-R-acosθ_(1i) )-2cos_j (r-R-acosθ_(1j) )]P_x

-[2sin_i (r-R-acosθ_(1i) )-2sin_j (r-R-acosθ_(1j) )P_y ]

-[2asinθ_(1i) -2asinθ_(1j) ]P_z +U_(ij) =0

Trong đó:

U_(ij) =(r-R-acosθ_(1i) )^2 +(asinθ_(1i) )^2 -(r-R-acosθ_(1j) )^2 -(asinθ_(1j) )^2

Tiến hành đơn giản hóa phương trình (2.19) bằng cách đặt ẩn phụ, phương trình mặt phẳng giao giữa s_1 với s_2 , s_3 là:

(2.20)

(2.21)

E_12 P_x +E_22 P_y +E_32 P_z +U_42 =0

E_13 P_x +E_23 P_y +E_33 P_z +U_43 =0

Với các tham số:

- E_12 =2cos_2 (r-R-acosθ_12 )-2cos_1 (r-R-acosθ_11 )
- E_22 =-[2sin_2 (r-R-acosθ_12 )-2sin_1 (r-R-acosθ_11 )]
- E_32 =-[2asinθ_12 -2asinθ_11 ]
- U_42 =(r-R-acosθ_12 )^2 +(asinθ_12 )^2 -(r-R-acosθ_11 )^2 -(asinθ_11 )^2
- E_13 =2cos_3 (r-R-acosθ_13 )-2cos_1 (r-R-acosθ_11 )
- E_23 =-[2sin_3 (r-R-acosθ_13 )-2sin_1 (r-R-acosθ_11 )]
- E_33 =-[2asinθ_13 -2asinθ_11 ]
- U_43 =(r-R-acosθ_13 )^2 +(asinθ_13 )^2 -(r-R-acosθ_11 )^2 -(asinθ_11 )^2

Từ 2 phương trình (2.20) và (2.21), mối quan hệ giữa tọa độ Px, Py, Pz được thể hiện như sau: Px = f( Pz ), Py = f( Pz ). Sau đó, thay thế Px , Py vào phương trình mặt cầu s1 được phương trình bậc 2 sau:

(2.22)

(1+(m_1 ^2)/(m_2 ^2)+(m_4 ^2)/(m_2 ^2))P_z ^2

+((2m_0 m_1)/(m_2 ^2)+(2m_3 m_4)/(m_2 ^2)-2m_5 cos_1 -(2m_1 m_5)/(m_2)sin_1 -(2am_4)/(m_2)sinθ_11 )P_z

+(m_5 ^2 - b^2 +(m_0 ^2)/(m_2 ^2)+(m_3 ^2)/(m_2 ^2)+(asinθ_11 )^2 -(2m_0 m_5)/(m_2)sin_1 -(2am_3)/(m_2)sinθ_11 )=0

Trong phương trình (2.22), các tham số:

- m_0 =E_32 U_43 -E_33 U_42
- m_1 =E_13 E_32 -E_12 E_33
- m_2 =E_22 E_33 -E_23 E_32
- m_3 =E_23 U_42 -E_22 U_43
- m_4 =E_12 E_23 -E_13 E_22
- m_5 =-(r-R-acosθ_11 )

Phương trình (2.22) sau khi được giải cho ra 2 giá trị Pz, mỗi giá trị Pz sẽ tìm được 1 bộ giá trị (Px, Py, Pz) . Vậy với mỗi bộ ( θ_11 , θ_12 , θ_13 ), thu được 2 vị trí P hình 2.8. Trong thực tế, do giới hạn về cơ khí, vì thế robot chỉ sử dụng giá trị Pz có giá trị như tổ hợp (-). Vì vậy chỉ có 1 bộ giá trị (Px, Py, Pz) được chấp nhận.

Hình 2.5 Hai cấu hình robot của bài toán động học thuận

# 2.6 Truyền động và tính toán tham số

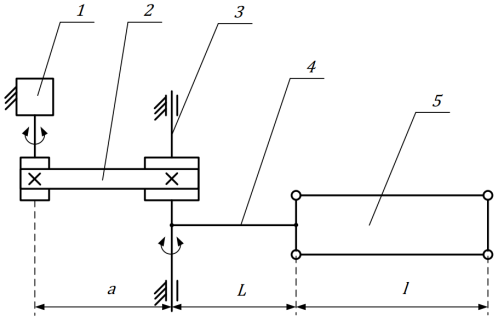
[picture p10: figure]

Để khâu công tác chuyển động được trong không gian, robot dùng 3 động cơ để dẫn động, động cơ bước được chọn làm động cơ dẫn động. Trong mô hình robot Delta X, nhà sản xuất dùng động cơ truyền động trực tiếp đến khâu chủ động do các thành phần chủ yếu được làm bằng nhựa nên khối lượng nhỏ, momen xoắn ở trục động cơ không lớn. Tuy nhiên, đối với mô hình robot được thực hiện trong đồ án, các thành phần chủ yếu được gia công từ kim loại nên khối lượng sẽ ảnh hưởng đến việc truyền động từ động cơ đến khâu chủ động, gây mất an toàn khi có quá tải. Để tránh hiện tượng này, động cơ truyền động cho các trục quay của mô hình robot có thể thông qua bộ truyền bánh răng hoặc bộ truyền đai. Vì chi phí thấp và lắp đặt dễ hơn bộ truyền bánh răng nên bộ truyền đai được lựa chọn. Tỉ số truyền của bộ truyền đai được chọn sơ bộ u = 3.

Hình 2.6 Chuỗi hoạt động nhánh thứ i của Robot Delta

Các thành phần chính cần tính toán và triển khai trong 1 chuỗi động học được thể hiện trong hình 2.6 bao gồm:

1 - Động cơ truyền động

2 - Bộ truyền đai

3 - Trục truyền động

4 - Khâu chủ động

5 - Khâu bị động

Bộ truyền đai (2) được lựa chọn để truyền động từ trục động cơ (1) đến trục dẫn động của robot Delta (3).

# 2.6.1 Lựa chọn thông số bộ truyền đai

Bộ truyền đai trong robot Delta đóng vai trò là cơ cấu truyền động trung gian giúp chuyển hóa mô-men xoắn từ động cơ đến các cánh tay chính một cách chính xác và hiệu quả. Việc sử dụng dây đai răng kết hợp với bánh răng đai giúp loại bỏ hiện tượng trượt, giảm thiểu độ rơ (backlash), từ đó đảm bảo độ chính xác lặp lại cực cao trong các tác vụ tốc độ lớn. Đặc biệt, cơ cấu này cho phép lắp đặt động cơ cố định trên khung trên, giúp giảm đáng kể khối lượng và quán tính của các bộ phận chuyển động, tạo điều kiện cho robot gia tốc nhanh, vận hành linh hoạt và êm ái hơn so với các bộ truyền động cơ khí trực tiếp.

Hình 2.7 Sơ đồ bộ truyền đai

Hiện nay, loại đai răng GT2 được sử dụng phổ biến trên thị trường trong các ứng dụng mô hình có momen xoắn không cao, kích thước nhỏ gọn. Do đó, mô hình đồ án sử dụng loại đai răng GT2 làm bộ truyền động.

Các thông số thiết kế bộ truyền đai được chọn như sau:

Bảng 2.1: Thông số được chọn và đã tính toán (xem ở mục Phụ lục):

Thông số | Ký hiệu | Đơn vị
Tỉ số truyền | u
Bước răng | p
Số răng bánh đai chủ động | Z1
Số răng bánh đai bị động | Z2
Đường kính bánh đai chủ động | d1
Đường kính bánh đai bị động | d2
Khoảng cách trục | a
Góc ôm đai | α
Chiều dài đai | ld

Từ các thông số tính toán, đai răng GT2 được chọn với bề rộng đai b = 6 mm, bước răng p = 2 mm.

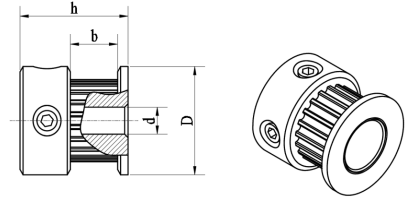
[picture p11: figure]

Hình 2.8 minh hoạt bánh đai chủ động GT2 với số răng là 20.

Hình 2.8 Minh họa bánh đai chủ động

Thông số bánh đai chủ động được thể hiện ở bảng 2.2

Bảng 2.2: Thông số bánh đai chủ động:

Thông số | Ký hiệu | Đơn vị
Chiều cao | h
Đường kính lỗ | d
Đường kính ngoài | D
Bề rộng | b

Hình 2.9 minh hoạt bánh đai bị động GT2 với số răng là 60.

Hình 2.9 Minh họa bánh đai bị động

Thông số bánh đai bị động được thể hiện ở bảng 2.3

Bảng 2.3: Thông số bánh đai bị động:

Thông số | Ký hiệu | Đơn vị
Chiều cao | h
Đường kính lỗ | d
Đường kính ngoài | D
Bề rộng | b

# 2.6.2 Kết quả các bài toán động học khi qua bộ truyền đai

Kết quả các bài toán động học được tính toán từ các phần trên là kết quả thu được khi chưa có bộ truyền động nhằm mục tính dễ hơn trong quá trình tính toán. Vậy khi đã chọn được bộ truyền động, kết quả động học sẽ thay đổi, ảnh hưởng trực tiếp đến góc quay θ_(1i) . Thế nên, việc tính toán kết quả sau cùng sẽ là bước quan trọng để có thể điều khiển chính xác Robot Delta.

Sau khi tính toán và có được các tham số chi tiết của bộ truyền đai, minh họa động học được biểu diễn như hình 2.10.

Hình 2.10 Minh họa bánh đai bị động

Điểm mạnh của việc bố trí các bánh đai như hình 2.10 sẽ giữ nguyên tham số như bán kính khâu đế R nơi chứa các động cơ.

- Bài toán động học thuận:

Bài toán cho ta biết tọa độ (Px; Py; Pz) với đầu vào là góc θ_(1i) . Vậy khi xét đầu vào trong quá trình điều khiển ta có công thức chuyển đổi:

(2.23)

θ_(1id) =uθ_(1i)

Trong đó:

- θ_(1id) là góc động cơ để đạt được góc θ_(1i)
- u là tỉ số truyền của bộ truyền động
- Bài toán động học nghịch:

Bài toán động học nghịch là then chốt trong quá trình điều khiển Robot nói chung và Robot Delta nói riêng.

Việc xác định góc θ_(1i) từ tọa độ điểm cho trước (Px; Py; Pz) là bước áp dụng cho hầu hết các bài toán thực tế của Robot Delta. Công thức (2.12) là kết quả cuối cùng cho bài toán động học nghịch được viết lại:

θ_(1i) =2tan^(-1) (t)

Suy ra góc động cơ cần phải thực hiện:

(2.24)

θ_(1id) =uθ_(1i) =2utan^(-1) (t)

# 2.7 Kiểm tra hoạt động và không gian làm việc

Kiểm tra vùng hoạt động hay không gian làm việc là một việc rất quan trọng trước khi vận hành thực tế. Bằng cách đưa các bài toán động học đã tính toán vào phần mềm mô phỏng, ta sẽ quan sát được một cách tổng quát vùng làm việc cũng như cách thức thực hiện của mô hình vật lý. Đó sẽ là cơ sở để điều khiển thực tế cũng như dễ dàng hơn trong quá trình kiểm nghiệm, thử sai.

Tham số quy chiếu từ mô hình vật lý:

Bảng 2.4: Tham số vật lý:

Ký hiệu | Giá trị | Đơn vị
R | 122 | mm
r | 40 | mm
a | 130 | mm
b | 298 | mm
u | 3

Phần mềm hỗ trợ cho bước này sẽ là Matlab. Matlab là một ngôn ngữ lập trình bậc cao chuyên về tính toán số, ma trận và có cả mô phỏng trực quan bằng khối được thực hiện trong Simulink.

Hình 2.11 Matlab_Simulink

# 2.7.1 Kiểm tra bài toán động học nghịch của mô hình

Kết hợp các công thức ở mục 2.3 và 2.4, ta được vào Matlab và tiến hành lập trình tính toán. Kết quả nhận được sẽ là:

Hình 2.12 Góc quay khớp chủ động

Từ hình 2.12, quỹ đạo chuyển động tương ứng với góc quay tại vị trí của mỗi khớp xoay đã đúng. Theta sẽ là góc mà khớp chủ động cần thực hiện đến một điểm tọa độ tương ứng.

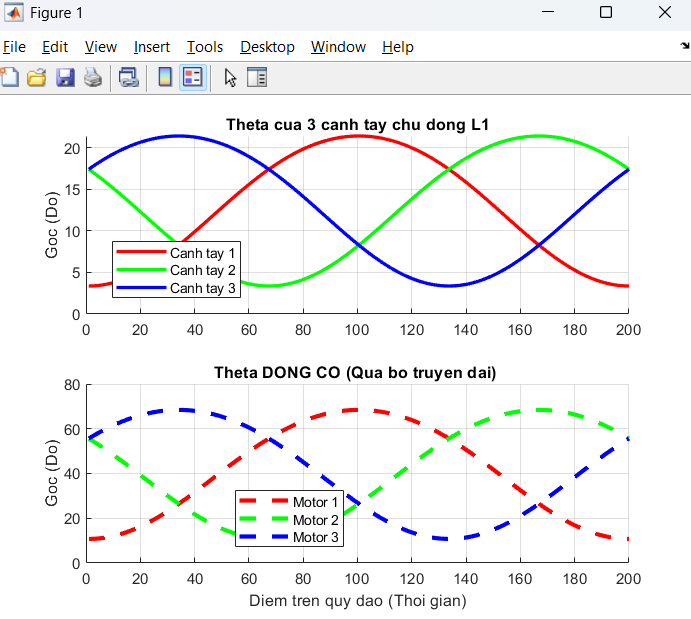
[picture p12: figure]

Tuy nhiên, việc mô phỏng trên mô hình vật lý chỉ chho biết góc quay của khớp. Ta cần tham chiếu giá trị của bộ truyền đai để rút ra kết luận cho số góc quay thực tế của động cơ cần phải điều khiển. Hình 2.13 minh họa cho góc quay của động cơ như sau:

Hình 2.13 Góc quay của động cơ thực tế

Từ kết quả mô phỏng, ta thấy góc quay động cơ cần thực hiện trùng khớp với công thức 2.23 đã tính toán. Điều này chứng minh công thức toán học cho động học nghịch đã đúng và chính xác.

# 2.7.2 Kiểm tra vùng làm việc của robot

Kiểm tra vùng làm việc là một điều kiện rất quan trọng để làm cơ sở điều khiển dự án. So với động học nghịch giúp biết được góc quay động cơ tại một điểm bất kỳ để xay dựng thuật toán điều khiển, động học sẽ giúp biết được không gian hoạt động ba chiều chiều robot, các vùng hoạt động ổn định và vùng giới hạn mà robot có thể thực hiện.

Dựa vào các công thức có trong mục 2.5, tiến hành tính toán trên Matlab bằng lập trình, ta thu được vùng làm việc như sau:

Hình 2.14 Không gian làm việc của Robot

Từ hình 2.14, vùng hoạt động đã đúng với công thức toán học đã làm được. Không gian làm việc đáp ứng khá tốt đủ để thiết lập các bài toán nghiên cứu.

Tiếp theo, ta sẽ tiến hành kiểm tra các điểm giới hạn của hệ thống:

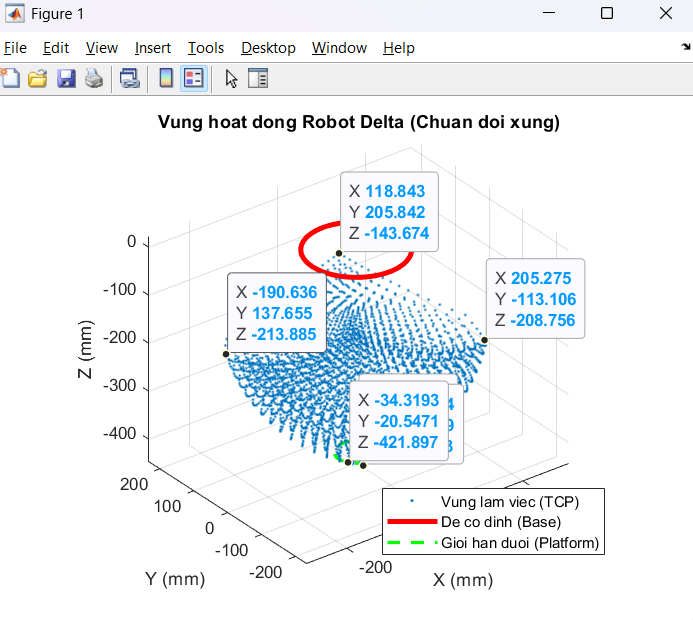
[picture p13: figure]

Hình 2.15 Không gian làm việc giới hạn

Từ các điểm tọa độ đã được đánh dấu trên hình 2.15, giới hạn của robot sẽ là vùng chứa hoặc lân cận các điểm này. Nếu điều khiển hoạt động vào phạm vi giới hạn sẽ sinh ra các hiện tượng nguy hiểm, nhẹ thì vào các điểm chết gây run hoặc đứng yên, nặng thì sẽ va đập cơ khí, hỏng động cơ và các bộ phận máy móc khác. Vì vậy, trong quá trình điều khiển cần xem xét vùng làm việc tối ưu và tránh các vùng giới hạn này.

# CHƯƠNG 3 NỘI DUNG

# 3.1 Sơ đồ nguyên lý điều khiển robot

Hình 4.1 Sơ đồ tổng quát hệ thống

Nguyên lý hoạt động tổng quát: Hệ thống bắt đầu bằng việc sử dụng Camera để quét dữ liệu hình ảnh, gửi trực tiếp về Laptop để xử lý thông tin bằng các thuật toán chuyên dụng (như nhận diện vật thể hoặc tính toán quỹ đạo). Sau khi tính toán, các tập lệnh điều khiển được truyền xuống Vi điều khiển thông qua giao thức UART. Tại đây, vi điều khiển đóng vai trò là "bộ não" trung gian, kết hợp lệnh từ máy tính với tín hiệu phản hồi từ 3 cảm biến Home (đảm bảo xác định chính xác điểm gốc và giới hạn an toàn) để xuất tín hiệu xung/hướng đến 4 bộ Driver TB6600. Các Driver này sau đó sẽ điều khiển 4 động cơ bước (Stepper Motors) thực hiện chuyển động cơ khí chính xác theo yêu cầu. Toàn bộ quá trình được nuôi bởi một Nguồn cấp hệ thống tập trung, phân tách điện áp 12VDC cho mạch lực (động cơ) và 5VDC cho mạch xử lý tín hiệu để đảm bảo tính ổn định và chống nhiễu.

# 3.1.1 Camera

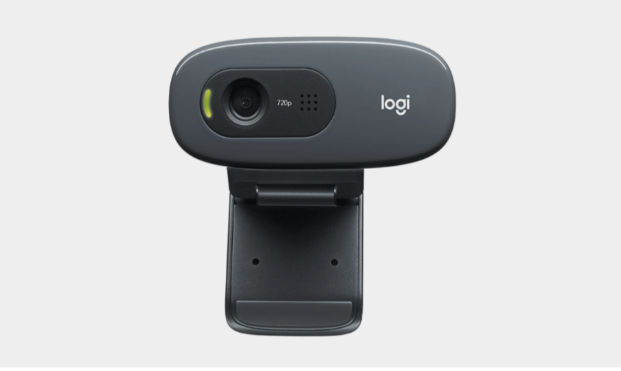
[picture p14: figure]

Camera trên thị trường hiện tại có quá nhiều loại. Để có thể lựa chọn một Webcam phù hợp cần hướng đến việc tham khảo các dự án đã từng dung Webcam. Trong số đó, Logitech C270 là một trong những lựa chọn khá phổ biến cho các dự án vừa và nhỏ, đảm bảo độ ổn định, chi phí, dễ sử dụng.

Hình 4.2 Webcam Logitech C270

Thông số kỹ thuật của Webcam Logitech C270:

- Độ phân giải tối đa 720pixel và 30 fps
- Tiêu cự cố định và thấu kính nhựa
- Tầm nhìn chéo (dFoV) 55 deg

Đánh giá:

Việc xử lý tốc độ của camera cần can thiệp qua nhiều yếu tố khách quan như độ sáng, tối ưu code, …

Khả năng 30 fps (30 khung hình trên giây) cho phép 1/30 giây ta sẽ lấy mẫu 1 lần, đồng nghĩa thông số dt = 1/30. Tốc độ này tạm vừa đủ với điều kiện lấy sai số cho bộ điều khiển.

# 3.1.2 Trung tâm tính toán và điều khiển chính Laptop

Hệ thống sẽ chạy với bộ não xử lý chính là Laptop_intel Core I7 thế hệ 12. Nhiệm vụ chính là mở camera, nhận sai số, tính toán, xuất giá trị gửi đến vi điều khiển.

Card đồ họa RTX 3050 cho phép hiển thị đồ họa mượt mà, nhanh và đủ tốt để xử lý tín hiệu.

Hình 4.3 Chip xử lý intel

# 3.1.3 Vi điều khiển STM32

Vi điều khiển trong hệ thống này có nhiệm vụ điều khiển động cơ quay với góc nhất định, thế nên cần có một tốc độ xử lý cao, bộ nhớ ổn, khả năng truyền nhận dữ liệu chính xác, điều khiển mượt mà.

Để đáp ứng tốt với mô hình này, STM32 là một sự lựa chọn đáng xem xét.

Vi điều khiển STM32 của STMicroelectronics (https://www.st.com/content/st_com/en/ecosystems/stm32-motor-control-ecosystem.html) là họ vi điều khiển 32-bit dựa trên lõi ARM Cortex-M, chia thành các dòng chính: Mainstream (https://www.google.com/search?q=Mainstream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) (F0, F1, G0, G4), High-Performance (https://www.google.com/search?q=High-Performance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) (F2, F4, F7, H7), Ultra-Low-Power (https://www.google.com/search?q=Ultra-Low-Power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) (L0, L1, L4, L5, U5) và Wireless (https://www.google.com/search?q=Wireless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) (WB, WL). Các dòng phổ biến nhất bao gồm F103, F401, F411 và F7/H7 cho ứng dụng xử lý cao. Riêng về dòng F1 thì ta có STM32 F103C6T8, một vi điều khiển có bộ nhớ 32KB, tốc độ xử lý 72MHz là rất mạnh mẽ, FLASH 64KB. Đây là một vi điều khiển tối ưu nhất về mặt chi phí, mạnh mẽ và ổn định.

Hình 4.4 STM32 F103C6T8 Blue Pill

# 3.1.4 Giao thức truyền thông

UART là giao thức truyền 3 dây phổ biến trên nhiều họ vi điều khiển nếu muốn 2 hoặc nhiều thiết bị truyền nhận dữ dữ liệu cho nhau một cách nhanh và chính xác. Trong đó, GND buột phải nối chung với nhau.

Hình 4.5 minh họa về UART

Giao thức này có sẵn trên STM32. Tuy nhiên, để có thể giao tiếp được với máy tính thì ta cần một modul chuyển đổi cổng USB. PL2303 là lựa chọn rất phù hợp và tương thích cao với STM32 F103.

Hình 4.6 UART STM32_PL2303

Chức năng chính của linh kiện này là tiếp nhận tín hiệu nhận được từ Laptop rồi chuyển đổi sang tín hiệu điều khiển.

# 3.1.5 Nạp dữ liệu cho vi điều khiển STM32

Khác với các loại vi điều khiển khác, STM32 F103 cần phải có một modul để nạp code. Có nhiều modul dung để nạp code cho vi điều khiển này, thông dụng và được đa số người sử dụng nhất vẫn là ST-Link.

Hình 4.7 ST-Link

# 3.1.6 Stepper NEMA 23

Động cơ bước (Stepper Motor) là một loại động cơ điện có khả năng di chuyển trục quay theo các bước nhỏ và chính xác thay vì quay liên tục như động cơ DC. Mỗi bước quay của động cơ tương ứng với một góc quay cố định, giúp người sử dụng dễ dàng kiểm soát vị trí, tốc độ và hướng quay thông qua các tín hiệu điều khiển.

Lựa chọn động cơ Step thông dụng, dễ làm, chi phí không quá cao, moment đủ lớn là những tiêu chí lựa chọn Stepper.

Các dòng động cơ bước (step motor) phổ biến trên thị trường được phân loại chủ yếu theo số pha (2, 3, 5 pha), cấu tạo rotor (hybrid, nam châm vĩnh cửu) hoặc kích thước khung (Nema 17, 23, 34). Các dòng thông dụng bao gồm Step 2 pha, Step 5 pha, Hybrid Stepper (mô-men cao) và các loại mini 28BYJ-48 cho dự án nhỏ.

Hệ thống sử dụng cơ cấu song song 3 chân được kết nối với 3 step với các cánh tay bằng kim loại có khối lượng khá lớn. Moment quán tính lớn. Từ đây ta lựa chọn NEMA 23 để làm dự án này với các lý do sau:

- Động cơ bước NEMA 23 là loại động cơ có kích thước mặt bích tiêu chuẩn 57x 57 (mm), cung cấp mô-men xoắn (torque) từ trung bình đến lớn, thường được sử dụng trong các hệ thống truyền động yêu cầu tải cao và độ chính xác bước đáng tin cậy.
- Lý tưởng cho các ứng dụng robot và cơ cấu truyền động chính xác, bao gồm các trục khớp nối của robot song song (Delta Robot), hệ thống chuyển động dùng bộ truyền đai - pulley (TPU/TMU), hoặc các cơ cấu bàn trượt định vị. Khả năng chịu tải và độ bền bỉ vượt trội khiến chúng trở thành lựa chọn hàng đầu cho các hệ thống tự động hóa vừa và nhỏ.
- Chi phí hợp lý, tối ưu hóa giữa hiệu suất mô-men xoắn và ngân sách đầu tư phần cứng.
- Khả năng phân giải vi bước cao (chế độ vi bước lên đến 1/32 hoặc cao hơn qua các dòng driver chuyên dụng như DM542, TB6600) vẫn đảm bảo duy trì đủ mô-men xoắn giữ và mô-men xoắn động lực cho hệ thống điều khiển mà không bị hiện tượng trượt bước (loss of steps).
- Vi điều khiển STM32F103 hoạt động với xung nhịp hệ thống lên đến 72MHz, cung cấp hiệu suất xử lý mạnh mẽ, đủ khả năng cấu hình các bộ định thời (Timer) phát xung PWM/Square-wave tần số cao, mượt mà và ổn định cho các chế độ vi bước phức tạp của NEMA 23.
- Dòng điện định mức hoạt động thường dao động từ 2.8A đến 4.2A (tùy thuộc vào chiều dài thân động cơ), mang lại lực kéo và lực giữ mạnh mẽ, đáp ứng tốt các yêu cầu thay đổi gia tốc nhanh của hệ thống.

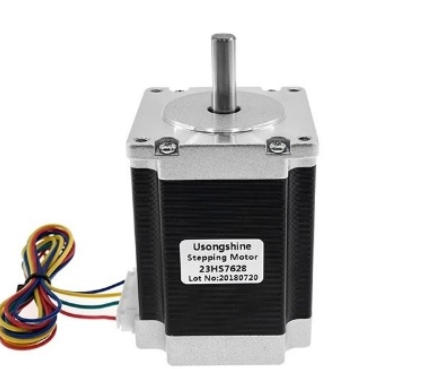
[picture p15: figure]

Hình 4.8 Stepper Motor Nema 23

# 3.1.7 Stepper NEMA 17

Để điều khiển bậc tự do thứ 4 (thường là trục xoay cổ tay - Roll/Yaw hoặc cơ cấu xoay khâu cuối) trong các hệ thống robot, việc lựa chọn động cơ bước NEMA 17 là một giải pháp cực kỳ phổ biến và tối ưu.

Động cơ bước NEMA 17 là dòng động cơ bước có kích thước mặt bích tiêu chuẩn là 42mm x 42mm. Đây là dòng động cơ "quốc dân" trong giới robot và máy in 3D nhờ sự cân bằng hoàn hảo giữa kích thước nhỏ gọn, trọng lượng nhẹ và khả năng cung cấp mô-men xoắn giữ (holding torque) vừa đủ cho các cơ cấu chấp hành quy mô nhỏ đến trung bình.

Lý do lựa chọn NEMA 17 cho bậc tự do thứ 4:

- Tối ưu hóa trọng lượng và giảm Quán tính (Crucial Factor). NEMA 17 chỉ nặng khoảng 200g - 350g (tùy chiều dài thân), giúp giảm tải trọng tĩnh lên các trục phía trước, tối ưu hóa năng lượng cho toàn bộ cánh tay.
- Kích thước nhỏ gọn, dễ bố trí cơ khí. Trục thứ 4 đòi hỏi sự linh hoạt cao để định hướng công cụ (kẹp, hút, đầu in...). Với kích thước mặt bích chỉ 42mm, NEMA 17 rất dễ tích hợp trực tiếp vào cụm cổ tay robot.
- Độ chính xác cao và khả năng giữ vị trí tốt giúp vật thể hoặc khâu kẹp không bị tự xoay dưới tác dụng của ngoại lực khi robot đang di chuyển.
- Mô-men xoắn vừa đủ cho tải khâu cuối
- Chi phí rẻ và hệ sinh thái hỗ trợ dồi dào
- Tóm lại: Lựa chọn NEMA 17 cho bậc tự do thứ 4 là bài toán tối ưu hóa giữa Trọng lượng ở đầu cần và Lực kéo. Nó đảm bảo cụm cổ tay robot vừa nhẹ, vừa chính xác, lại tiết kiệm chi phí phần cứng một cách hiệu quả nhất.

Hình 4.9 Step NEMA 17

# 3.1.8 Driver TB6600

Việc lựa chọn Driver điều khiển Step là một vấn đề cần giải quyết. hệ thống cần phải xử lý ở tốc độ cao thêm phải đảm bảo đột mượt chuyển động thì nên cân nhắc trước khi chọn driver tương thích.

Các driver phổ biến mạnh mẽ để điểu khiển step trên thị trường như TB6600, A4988, DM542, …. Tiêu chí lựa chọn sẽ là tạo xung nhịp cao, dòng ổn định, dễ sử dụng và chi phí phải chăng. Dựa vào đó ta sẽ chọn TB6600 để thực hiện.

Hình 4.10 Driver TB6600

- Chỉnh vi bước:

Bảng 4.1 Bảng tham chiếu vi bước trên TB6600

Vi bước | SW1 | SW2 | SW3
FULL | 1 | 1 | 0
1/2 | 1 | 0 | 1
1/4 | 1 | 0 | 0
1/8 | 0 | 1 | 0
1/16 | 0 | 0 | 1
1/32 | 0 | 0 | 0

- Chỉnh dòng điều khiển:

Bảng 4.2 Bảng tham chiếu dòng điều khiển TB6600

Dòng điện | SW4 | SW5 | SW6
0.5 - 0.7A | 1 | 1 | 1
1.0 - 1.2 A | 1 | 0 | 1
1.5 - 1.7 A | 1 | 1 | 0
2.0 - 2.2 A | 1 | 0 | 0
2.5 - 2.7 A | 0 | 1 | 1
2.8 - 2.9 A | 0 | 0 | 1
3.0 - 3.2 A | 0 | 1 | 0
3.5 – 4.0 A | 0 | 0 | 0

Dựa vào bảng 4.1 và 4.2, ta tiến hành chỉnh vi bước và dòng cho các động cơ như sau:

- Đối với NEMA 23, do là động cơ điều khiển qua trọng nhất trong robot delta, cần một moment đủ tốt nhưng vẫn đảm bảo được độ chính xác, do đó, vi bước lựa chọn sẽ là 1/16 nghĩa là 3200 xung cho một vòng quay 360 độ. Dòng điều khiển ổn định cho loại này sẽ là 2.0 – 2.2 A
- Đối với NEMA 17, do là khâu chấp hành, cần một moment vừa đủ. Vì vậy, vi bước lựa chọn sẽ là 1/8 nghĩa là 1600 xung cho một vòng quay 360 độ. Dòng điều khiển ổn định cho loại này sẽ là 1.5 – 1.7 A

# 3.1.9 Công tắt hành trình

Đối với cấu trúc robot song song như Robot Delta, việc xác định chính xác góc vị trí ban đầu của cả ba cánh tay chủ động (Active Arms) là điều kiện tiên quyết mang tính sống còn để các thuật toán động học ngược (Inverse Kinematics) có thể tính toán chính xác tọa độ khâu cuối E(x, y, z). Công tắc hành trình được lắp đặt cố định tại giới hạn trên của từng trục khớp nhằm mục đích thiết lập một điểm tham chiếu vật lý tuyệt đối cho hệ thống trước khi robot bước vào chu trình vận hành. Khi bắt đầu quá trình khởi tạo, ba động cơ bước sẽ độc lập hoặc đồng thời điều khiển các cánh tay chủ động di chuyển ngược lên phía trên với vận tốc không đổi cho đến khi vấu cơ khí chạm vào cần gạt của công tắc hành trình. Tín hiệu phản hồi tức thời từ các công tắc này không chỉ đóng vai trò như một cơ chế bảo vệ an toàn giúp robot không bị quay quá giới hạn cơ khí gây gãy vỡ cấu trúc đai truyền, mà còn cung cấp mốc tọa độ ba góc θ gốc chuẩn, làm nền tảng để bộ điều khiển đồng bộ hóa toàn bộ không gian làm việc của robot.

Hình 4.11 Công tắc hành trình

# 3.1.10 Nguồn cấp vi điều khiển và cảm biến ngoại vi

Nguồn 5VDC đóng vai trò là nguồn cấp phôi (nguồn đầu vào) cực kỳ quan trọng cho vi điều khiển STM32. Từ nguồn 5V này, mạch sẽ hạ áp xuống 3.3V để nuôi chip STM32, đồng thời nguồn 5V cũng được dùng để nuôi các ngoại vi khác như cảm biến, công tắc hành trình hoặc mạch nạp.

Hình 4.12 Adapter 5VDC

# 3.1.11 Nguồn cấp cho driver TB6600

Đối với linh kiện này, không phải nguồn nào cũng phù hợp để sử dụng. Trong điều kiện hoạt động lâu, liên tục của stepper, TB6600 cần một nguồn cấp ổn định, có cường độ dòng điện lớn.

TB6600 là một driver sử dụng nguồn từ 12 đến 24V. Ngưỡng dòng điện đỉnh là 4A để cấp cho stepper, đường kính dây phải từ 0.5 trở lên.

Tính toán dòng tổng:

- NEMA 23: 2,2 x 3 = 6,6 A
- NEMA 17: 1,7 x 1 = 1,7 A
- Quạt tản nhiệt 12 V: 0,25 A
- Motor hút khí 12 V: 2 x 2 = 4 A
- Motor có giảm tốc 12 V - 2 A
- Total = 6,6 + 1,7 + 0,25 + 4 + 2 = 14,55 A

Dựa vào dòng tổng đã tính toán, ta sẽ chọn một nguồn với hiệu điện thế vừa phải nhưng dòng phải cao. Tiêu biểu trong các dự án có dòng cao như vậy và rất được nhiều người sử dụng vì tính đa năng, mạnh mẽ có thể kể đến là nguồn tổ ong 12V – 20A.

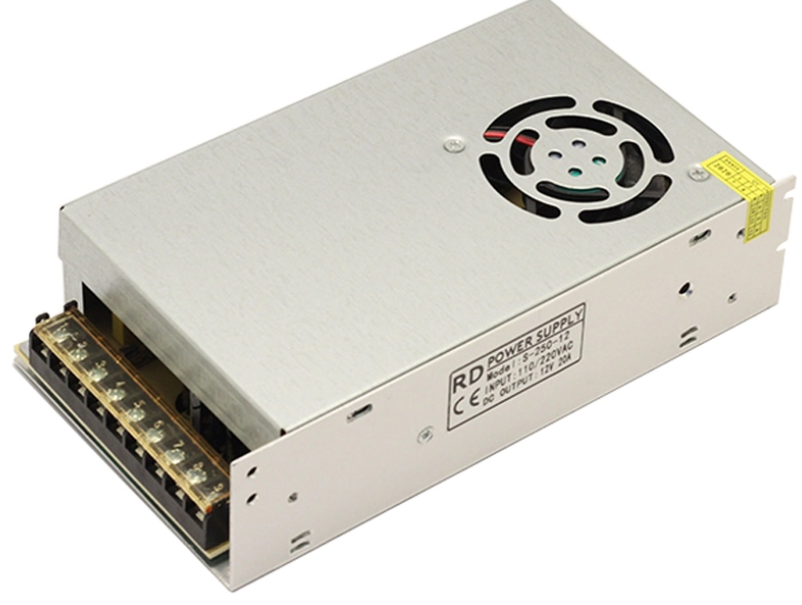
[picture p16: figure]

Hình 4.13 Nguồn tổ ong 12VDC – 20A (Input 220VAC)

Khi sử dụng nguồn tổ ong 12V 20A cấp cho driver TB6600, lưu ý cốt lõi là phải xử lý triệt để hiện tượng nhiễu xung dòng lớn bằng cách tách biệt hoàn toàn GND động lực (GND nguồn tổ ong) với GND tín hiệu của vi điều khiển, đồng thời tận dụng cách ly quang (Optocoupler) trên các chân PUL, DIR, ENA của driver. Để bảo vệ hệ thống khỏi dòng điện ngược (Back-EMF) sinh ra khi động cơ phanh hoặc đảo chiều gây sụt áp reset chip,. Cuối cùng, vì nguồn 20A có công suất rất khỏe, bắt buộc phải gạt các công tắc hành trình (Dip Switch) trên thân TB6600 để giới hạn dòng điện đỉnh (Current) chính xác theo thông số của loại động cơ sử dụng, kết hợp bấm đầu cos chắc chắn tại các điểm đấu nối để tránh hiện tượng phóng tia lửa điện do tiếp xúc kém.

# 3.2 Thiết kế và xây dựng mô hình cơ khí

Để thực hiện lý thuyết đã được đặt ra ở các mục trên, ta tiến hành thiết kế mô hình và xây dựng cấu trúc Robot hoàn thiện nhằm hiện thực hóa các mục tiêu xây dựng.

Auodesk Inventor là phần mềm thiết kế cơ khí 3D chuyên nghiệp (CAD), tập trung vào việc xây dựng mô hình khối (solid modeling) và thiết kế hệ thống máy móc phức tạp.

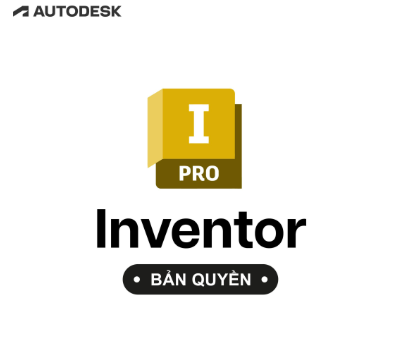
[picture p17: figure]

Thay vì chỉ vẽ đường nét, Inventor cho phép bạn tạo ra các chi tiết (Part), lắp ráp chúng thành một bộ máy hoàn chỉnh (Assembly) và mô phỏng chuyển động hoặc phân tích ứng lực ngay trên máy tính. Đây là công cụ cực kỳ mạnh mẽ để hiện thực hóa các bản vẽ kỹ thuật từ ý tưởng thành mô hình thực tế với độ chính xác tuyệt đối.

Hình 4.14 Inventor Professional

# 3.2.1 Đế cố định

Đế cố định là vị trí rất quan trọng trong mô hình Robot Delta. Việc thiết kế kích thước chính xác là một trong những biện pháp tối ưu để có thể dễ dàng lắp ráp cũng như quá trình điều khiển sau này.

Không chỉ đòi hòi chính xác về kích thước, các vị trí lắp ráp các cụm động cơ cũng đòi hỏi độ chính xác cực cao. Về bản chất hình học của Robot Delta, vị trí đặt các khớp xoay tại khâu chủ động có quan hệ rất mật thiết với động học của robot. Các khớp phải được lắp một vị trí cố định và lệch nhau 120 độ. Điều này đồng nghĩa với thiết kế vị trí gá các cụm động cơ phải chính xác, chắc chắn và lệch nhau chuẩn 120 độ thì điều khiển robot mới đạt được độ chính xác cao.

Do các cụm động cơ điều khiển tương đối nặng nên độ dày và độ chắc chắn cũng là vấn đề cần được làm tốt. Chất liệu được lựa chọn sẽ là các tấm polime cứng và gia công bằng phương pháp cắt lazer. Bề dày 8 mm gồm hai tấm 2 mm và một tấm 4 mm được liên kết bằng ốc vít sẽ đảm bảo được độ chắc chắn khi gá các cụm động cơ vào đế.

Hình 4. Tổng quan đế trên

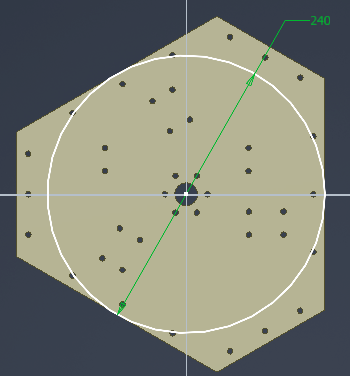
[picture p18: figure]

Hình 4. Bán kính đế R = 120

Hình 4. Vị trí gá cụm động cơ

# 3.2.2 Đế di động

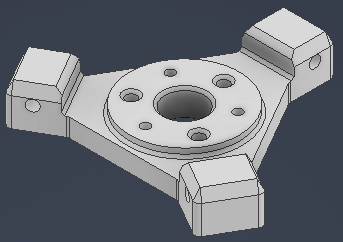
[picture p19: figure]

Hình 4. Đế dưới

Đế dưới là hay đế di động được xem là điểm cuối thực hiện robot. Trong Robot Delta, đế dưới là cụm thực hiện các chuyển động trong không gian nhằm thực hiện các tác vụ điều khiển. Với cấu trúc cơ bản, đế dưới có thể di chuyển theo ba phương x, y, z trong không gian. Lúc này, không gian hoạt động của đế dưới sẽ phụ thuộc vào tọa độ cần điều khiển nhưng phải đáp ứng điều kiện nằm trong không gian hoạt động cho phép.

Cũng giống đến trên, vị trí khớp nối phải đảm bảo lệch nhau 120 độ, kích thước thiết kế phải chính xác vì liên quan mật thiết đến động học điều khiển.

Hình 4. Bán kính đế dưới r = 40

Hình 4. Độ lệch các khớp

Ngoài ra, đế di động còn được thiết kế các lỗ định vị nhằm gá các thiết bị điều khiển khác. Điều này là bắt buộc khi muốn điều khiển các tác vụ nhất định với nhiều bài toán xử lý khác nhau.

# 3.2.3 Khâu chủ động

Khâu chủ động hay Link 1 trong Robot Delta là vị trí chuyển động rang buộc. Được kết nối cứng vào động cơ hoặc qua thêm các thiết bị truyền động phù hợp. Động cơ quay n vòng, khâu chủ động cũng sẽ quay số vòng tương ứng theo tỉ lệ, có thể là 1 : 1, 1 : 3, … tùy vào tỉ số truyền của bộ truyền động.

Kích thước của Link 1 rất quan trọng nên cũng cần thiết kế chính xác. Kích thước của Link 1 sẽ ảnh hưởng đến không gian làm việc của robot rất nhiều. Và để đảm bảo ổn định không gian làm việc, thông số khâu này cần phải được làm rõ nhằm làm tiền đề xây dựng các bài toán điều khiển cũng như tránh các sự cố hỏng phần cứng do vượt quá vùng hoạt động của robot.

Hình 4. Khâu chủ động

Hình 4. Độ dài L = 130 mm

Vị trí gá Link 1 đến các cụm động cơ sẽ là các lỗ d=3,2 mm có tác dụng gắn vào khớp nối mặt bích.

# 3.2.4 Khâu bị động

Khâu bị động Link 2 của robot là một khâu chuyển động bị phụ thuộc vào chuyển động của động cơ. Trong thực tế, khâu này không trực tiếp chuyển động trong không gian, nó chỉ chuyển động khi Link 1 chuyển động và phạm vi di chuyển nằm trong phạm vi cho phép.

Vì thông số độ dài của khâu ảnh hưởng đến các phép tính trong động học nên cũng cần được thiết kế chính xác.

Cấu tạo gồm 3 phần:

- Ống kim loại:

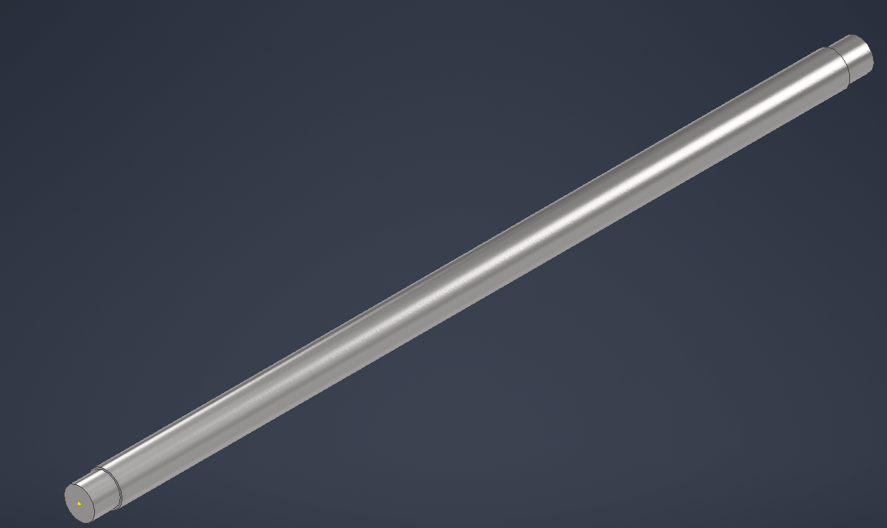
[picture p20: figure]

Hình 4. Khâu bị động

Hình 4. Chiều dài

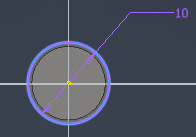
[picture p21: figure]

Hình 4. Đường kính vòng ngoài ống kim loại

Hình 4. Đường kính đoạn dẫn khớp nối

- Ổ bi mắt trâu:

Hình 4. Ổ bi mắt trâu

Hình 4. Đường kính lỗ

- Khớp nối:

Hình 4. Khớp nối

Tiến hành lắp ráp 3 chi tiết này lại với nhau, ta có được Link 2 đầy đủ với chiều dài l=298 mm .

Hình 4. Link 2, l=298 mm

# 3.2.5 Cụm bộ truyền động

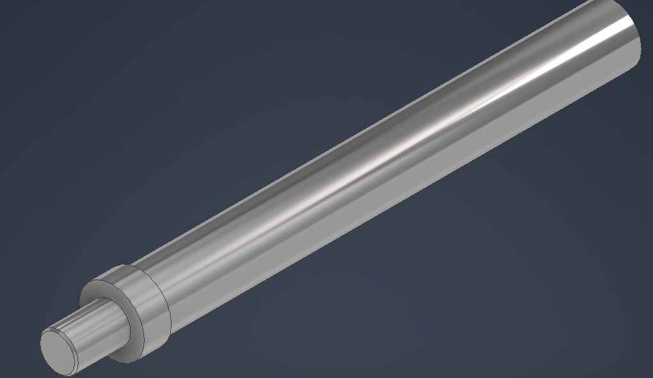
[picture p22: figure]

Hình 4. Đế trên

Hình 4. Đế trên

Hình 4. Đế trên

Hình 4. Đế trên

# 3.2.7 Ổ trượt vòng bi

Hình 4. Đế trên

Hình 4. Đế trên

# 3.2.8 Mặt bích

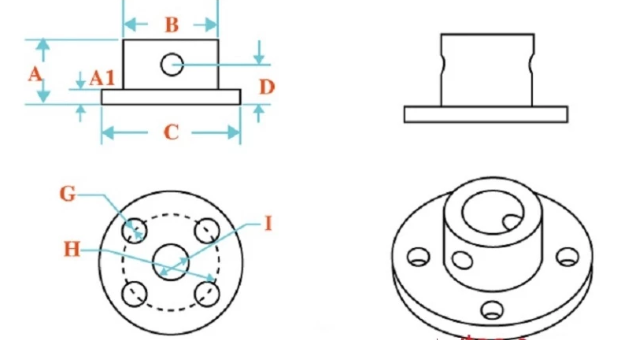
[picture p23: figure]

Hình 4.14 Inventor Professional

Hình 4.14 Inventor Professional

Hình 4.14 Inventor Professional

# 3.2.9 Khung đỡ

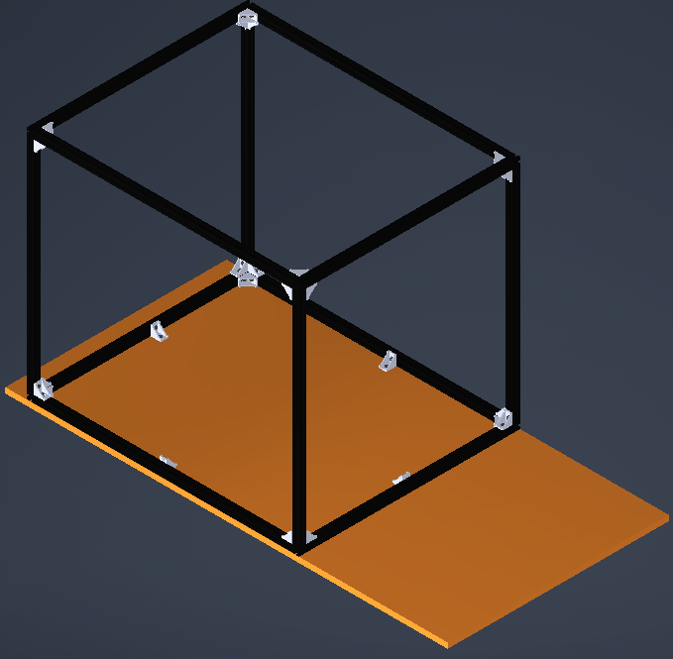
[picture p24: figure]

Hình 4.14 Inventor Professional

# 3.2.10 Chốt khoảng cách ở khớp

Hình 4.14 Inventor Professional

# 3.2.11 Lắp ráp mô hình

# 3.3 Thiết kế và xây dựng hệ thống điện

# 3.3.1 Mạch khởi động trực tiếp

Hình 4.14 Inventor Professional

- Nguyên lý hoạt động của mạch:
- MCB (Miniature Circuit Breaker):

Hình 4.14 Inventor Professional

- Contactor (khởi động từ):

Hình 4.14 Inventor Professional

- E_STOP (dừng khẩn cấp):

Hình 4.14 Inventor Professional

- Công tắc tay gạt 2 vị trí:

Hình 4.14 Inventor Professional

- LED cảnh báo 220VAC:

Hình 4.14 Inventor Professional

- Nút nhấn ON:

Hình 4.14 Inventor Professional

- Nút nhấn OFF:

Hình 4.14 Inventor Professional

# 3.3.2 Mạch điều khiển trung tâm

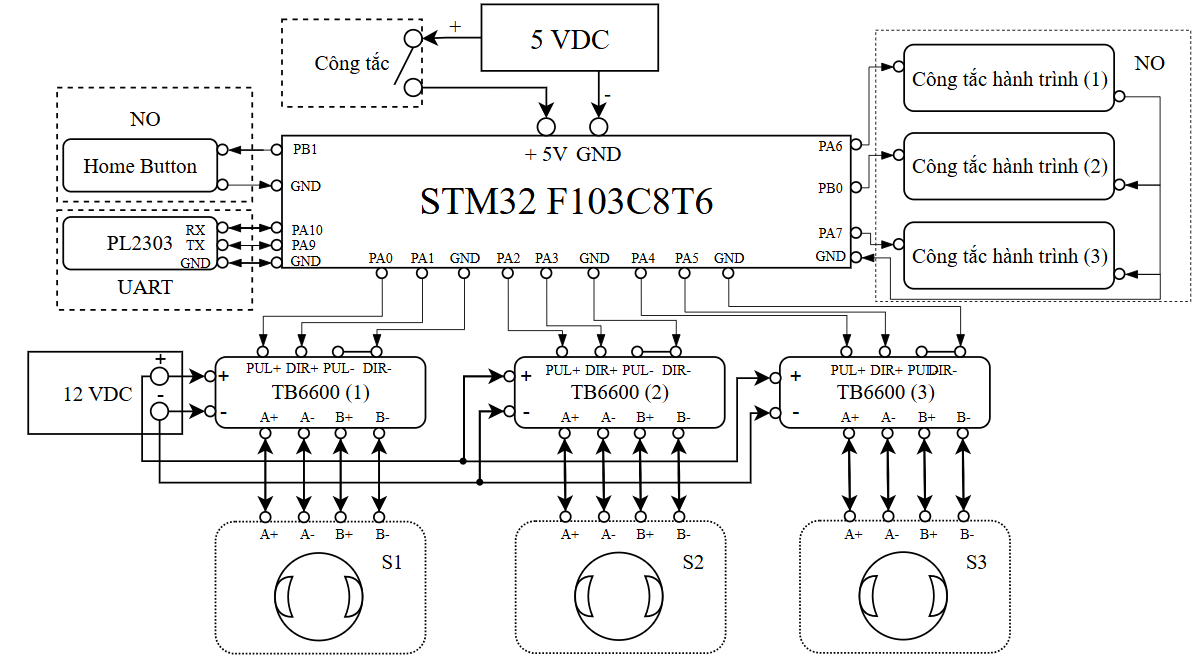
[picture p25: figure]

Hình 4.14 Inventor Professional

- Nguyên lý hoạt động của mạch:

# 3.3.3 Mạch điều khiển bậc tự do thứ 4 và các thiết bị ngoại vi

Hình 4.14 Inventor Professional

# CHƯƠNG 4 XÂY DỰNG THUẬT TOÁN ĐIỀU KHIỂN CHO HỆ THỐNG

# 4.1 Xử lý ảnh

Xử lý ảnh (Image Processing) là một lĩnh vực giao thoa then chốt giữa khoa học máy tính, kỹ thuật điện tử và toán học ứng dụng, tập trung vào việc nghiên cứu và phát triển các thuật toán chuyên sâu để tác động vào cấu trúc dữ liệu của hình ảnh kỹ thuật số. Quá trình này không chỉ đơn thuần là thay đổi diện mạo bên ngoài mà còn bao gồm một chuỗi các thao tác phức tạp từ tiền xử lý để loại bỏ nhiễu, tăng cường độ tương phản, cho đến việc trích xuất các đặc trưng hình học và phân tích ngữ cảnh của từng điểm ảnh. Mục tiêu cốt lõi của xử lý ảnh hướng tới hai nhánh ứng dụng chính: một mặt là tối ưu hóa thị giác để cung cấp những hình ảnh sắc nét, trung thực hơn cho sự quan sát và đánh giá của con người; mặt khác là cung cấp dữ liệu đầu vào chuẩn xác cho các hệ thống thị giác máy tính, giúp máy móc có khả năng tự động hóa việc nhận dạng thực thể, phân loại đối tượng và đưa ra các quyết định điều khiển thông minh trong những môi trường thực tế phức tạp như xe tự lái, y tế hay dây chuyền sản xuất công nghiệp.

Pycharm là một môi trường lập trình dung riêng cho ngôn ngữ Python. Đây là một phần mềm co cộng đồng sử dụng lớn, thư viện hỗ trợ rộng rãi. Python là ngôn ngữ lập trình phổ biến hàng đầu nhờ đặc tính ôn hòa, dễ sử dụng và lập trình. Đặc biệt, nó được áp dụng hầu hết trong các mảng xử lý thuật toán. Opencv là một thư viện mạnh mẽ về xử lý ảnh và những thuật toán liên quan.

Hình 2.38 Pycharm

OpenCV (Open Source Computer Vision Library) không chỉ đơn thuần là một bộ công cụ lập trình, mà còn là nền tảng mã nguồn mở đồ sộ và phổ biến nhất thế giới trong lĩnh vực thị giác máy tính và xử lý hình ảnh kỹ thuật số. Kể từ khi được khởi xướng bởi Intel vào năm 1999 với mục tiêu thúc đẩy các ứng dụng chuyên sâu về CPU, thư viện này đã trải qua hơn hai thập kỷ phát triển không ngừng để trở thành một hệ sinh thái tiêu chuẩn, quy tụ hàng ngàn thuật toán tối ưu hóa từ cơ bản như lọc nhiễu, biến đổi hình học đến các kỹ thuật tiên tiến như nhận diện khuôn mặt, theo dõi đối tượng thời gian thực và tích hợp sâu các mô hình học máy (Machine Learning). Với khả năng hỗ trợ đa ngôn ngữ từ C++, Python đến Java và tương thích trên nhiều hệ điều hành khác nhau, OpenCV đóng vai trò là "đôi mắt" và "bộ não" nhân tạo, cung cấp các giải pháp tính toán hiệu năng cao giúp máy tính có khả năng trích xuất thông tin định lượng, phân tích ngữ cảnh từ dữ liệu hình ảnh hoặc video phức tạp, qua đó phục vụ đắc lực cho các hệ thống tự động hóa, robot thông minh và phân tích dữ liệu thị giác quy mô lớn.

# 4.1.1 Lý thuyết về xử lý ảnh

Ảnh số là tập hợp hữu hạn điểm ảnh với mức xám phù hợp dùng để mô tả ảnh gần với ảnh thật. Số điểm ảnh xác định độ phân giải của ảnh. Độ phân giải càng cao thì càng thể hiện rõ nét các đặc điểm trong ảnh và làm cho ảnh trở nên thực và sắc nét hơn.

Ảnh số được lưu dưới dạng ma trận 2 chiều chứa dữ liệu của các điểm ảnh, mỗi điểm ảnh được xác định nhờ vào tọa độ [i, j] trong hệ tọa độ ảnh như thể hiện ở hình 2.39. Tùy vào số kênh màu và khoảng giá trị của các điểm ảnh mà ảnh được phân ra làm 3 loại chính là ảnh màu, ảnh xám và ảnh nhị phân. Trong ảnh màu, có nhiều không gian màu như HSV, RGB, CMYK, … Trong đó không gian màu RGB là không gian màu phổ biến được sử dụng trong máy tính, máy ảnh, điện thoại và một số thiết bị kỹ thuật số khác. Do đó đồ án này tập trung vào ảnh màu RGB, ảnh xám và ảnh nhị phân.

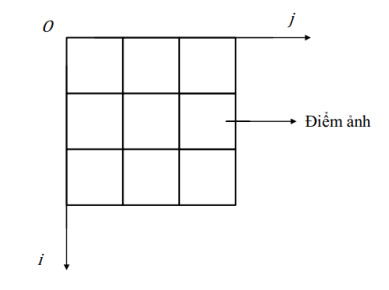
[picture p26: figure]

Hình 2.39 Hệ tọa độ ảnh

- Ảnh màu RGB

Hình 2.40 Không gian màu RGB

Ảnh màu là một tập hợp các ma trận nhiều điểm ảnh trong khôn gian màu, mỗi điểm ảnh lưu giá trị của các kênh màu cơ bản là đỏ (R), xanh lục (G) và xanh lam (B), sự kết hợp giá trị của 3 kênh màu sẽ tạo ra các màu sắc khác nhau như minh họa ở hình 4.2. Nếu dùng 24 bit để lưu giá trị của một điểm ảnh, tức là 8 bit cho kênh R, 8 bit cho kênh G và 8 bit cho kênh B thì mỗi kênh màu sẽ có 28 = 256 mức màu, tương ứng với mức 0 là màu tối nhất và mức 255 là màu sáng nhất của kênh màu đó. Kết hợp 3 kênh màu sẽ tạo ra hơn 16 triệu màu sắc khác nhau.


- Ảnh HSV

Hình 2.40 Không gian màu HSV

Không gian màu HSV (Hue - Saturation - Value) là một hệ thống biểu diễn màu sắc dựa trên cách con người cảm nhận, được sử dụng rộng rãi trong OpenCV nhờ khả năng tách biệt thông tin màu sắc nguyên bản khỏi các yếu tố ánh sáng. Khác với mô hình RGB/BGR phụ thuộc vào sự pha trộn các kênh màu vật lý, HSV định nghĩa màu sắc qua ba thông số: Hue (Sắc thái) quy định loại màu trong dải 0–179, Saturation (Độ bão hòa) đại diện cho độ đậm nhạt từ 0–255, và Value (Giá trị) thể hiện cường độ sáng từ 0–255. Đặc điểm này giúp HSV trở thành công cụ đắc lực cho các bài toán phân đoạn và nhận diện vật thể theo màu sắc, vì nó cho phép lập ngưỡng (thresholding) chính xác vùng màu mục tiêu mà không bị ảnh hưởng quá nhiều bởi sự thay đổi của điều kiện ánh sáng môi trường hay bóng đổ.

- Ảnh xám

Hình 2.41 Ảnh xám

Ảnh xám (Grayscale) là một loại hình ảnh kỹ thuật số mà trong đó giá trị của mỗi điểm ảnh (pixel) chỉ mang thông tin về cường độ ánh sáng thay vì thông tin màu sắc phức tạp như các hệ màu RGB hay HSV. Trong cấu trúc dữ liệu của một ảnh xám tiêu chuẩn, nếu chúng ta sử dụng độ sâu màu 8 bit để lưu trữ cho mỗi điểm ảnh, thì theo nguyên lý tổ hợp, mỗi pixel sẽ có khả năng biểu diễn 2⁸ = 256 sắc thái mức xám khác nhau. Dải giá trị này được quy định chặt chẽ trong khoảng từ 0 đến 255, trong đó, giá trị 0 đại diện cho màu đen tuyệt đối (mức tối nhất), giá trị 255 đại diện cho màu trắng thuần khiết (mức sáng nhất), và các giá trị nằm giữa sẽ biểu thị các sắc độ xám chuyển tiếp từ đậm đến nhạt.

- Ảnh nhị phân

Hình 2.42 Ảnh nhị phân

Ảnh nhị phân (Binary Image) là một dạng biểu diễn hình ảnh kỹ thuật số đặc biệt, trong đó cấu trúc dữ liệu của mỗi điểm ảnh (pixel) được tối giản hóa đến mức tối đa để chỉ chứa một trong hai giá trị trạng thái duy nhất. Mặc dù về mặt toán học, mỗi điểm ảnh thường được lưu trữ dưới dạng 1 bit để đại diện cho giá trị 0 hoặc 1, nhưng trong các thư viện xử lý ảnh phổ biến như OpenCV, chúng thường được ánh xạ sang dải 8-bit để tương thích với các định dạng hiển thị tiêu chuẩn. Khi đó, giá trị cường độ 0 sẽ đại diện cho màu đen (thường là nền) và giá trị 255 (tương đương với mức logic 1) sẽ đại diện cho màu trắng (thường là đối tượng cần tách lọc).

Việc chuyển đổi từ ảnh xám sang ảnh nhị phân thông qua các kỹ thuật phân ngưỡng (thresholding) là một bước ngoặt quan trọng trong quy trình thị giác máy tính. Nó giúp loại bỏ hoàn toàn các chi tiết thừa và sự biến thiên độ sáng không cần thiết, chỉ để lại hình dáng hình học (silhouette) và các đường nét biên của đối tượng. Nhờ vào sự đơn giản hóa này, các thuật toán sau đó như tìm kiếm đường bao (contour detection), tính toán diện tích, hay nhận diện ký tự (OCR) có thể thực hiện với tốc độ cực nhanh và độ chính xác cao hơn, do máy tính chỉ cần xử lý sự phân tách rõ rệt giữa hai vùng tương phản tuyệt đối.

# 4.1.2 Hiệu chuẩn máy ảnh (Camera Calibration)

Hiệu chuẩn máy ảnh (Camera Calibration) là quá trình xác định các tham số kỹ thuật bên trong (tiêu cự, tâm ảnh, hệ số biến dạng) và các tham số bên ngoài (vị trí, hướng) của camera so với thế giới thực.

Công dụng chính của quá trình này là loại bỏ các hiện tượng biến dạng hình ảnh (như biến dạng hình cầu - Barrel Distortion thường làm cong các đường thẳng ở rìa ảnh) và thiết lập mối liên hệ toán học giữa tọa độ điểm ảnh với tọa độ thực tế. Trong các hệ thống như robot Delta của bạn, hiệu chuẩn giúp chuyển đổi chính xác vị trí vật thể mà camera nhìn thấy thành tọa độ mà cánh tay robot có thể gắp được.

Có ba nhóm phương pháp chính dựa trên đối tượng tham chiếu:

- Dựa trên bàn cờ (Chessboard/Checkerboard): Sử dụng một tấm phẳng có các ô vuông đen trắng xen kẽ. Đây là phương pháp phổ biến và chính xác nhất nhờ khả năng xác định các góc giao điểm (corners) với độ chính xác dưới pixel.
- Dựa trên vật thể 3D (3D Calibration Object): Sử dụng các khung có các điểm đặc trưng nằm trên nhiều mặt phẳng khác nhau. Phương pháp này rất chính xác nhưng khó chế tạo thiết bị chuẩn.
- Tự hiệu chuẩn (Self-Calibration): Dựa trên sự chuyển động của camera trong môi trường tĩnh để ước lượng tham số mà không cần vật chuẩn. Phương pháp này kém ổn định và thường được dùng trong các thuật toán SLAM phức tạp.

Như vậy, phương pháp hiệu chỉnh bằng bàn cờ sẽ giúp dễ dàng hơn trong quá trình hiệu chuẩn, tiết kiệm thời gian và dễ dàng nghiên cứu hơn trong quá trình triển khai.


Hình 2.43 Bàn cờ 9 x 7

Cơ sở cốt lõi của việc chọn bàn cờ nằm ở tính xác định hình học của các góc cạnh, nơi các cạnh đen và trắng giao nhau tạo ra các đặc trưng toán học cực kỳ ổn định cho thuật toán trích xuất. Khi lựa chọn bàn cờ, cần tuân thủ các tiêu chí khắt khe: thứ nhất, bề mặt bàn cờ phải tuyệt đối phẳng và không bị phản xạ ánh sáng (nên sử dụng bề mặt nhám/mờ) để tránh sai lệch tọa độ do chói sáng; thứ hai, các ô vuông phải có kích thước hoàn toàn đồng nhất và khoảng cách giữa các góc phải được đo đạc chính xác tuyệt đối để làm dữ liệu đầu vào cho quá trình tính toán. Một bàn cờ đạt chuẩn không chỉ giúp quá trình hiệu chuẩn hội tụ nhanh hơn, mà còn là yếu tố quyết định để loại bỏ triệt để các biến dạng hình học (đặc biệt là biến dạng xuyên tâm) vốn thường gặp trên các ống kính góc rộng thường dùng trong các bài toán thị giác máy tính.

Đối với các hệ thống cần độ chính xác cao như robot Delta hay hệ thống cân bằng, việc sử dụng bàn cờ có kích thước ô vuông 10 mm với cấu trúc 9x7 góc (tương ứng 10x8 ô vuông) là sự lựa chọn tối ưu. Kích thước 10 mm đủ nhỏ để đảm bảo bạn có thể thu được nhiều điểm dữ liệu trong một khung hình mà không làm giảm độ phân giải của từng góc, trong khi cấu trúc 9x7 góc cung cấp 63 điểm nút riêng biệt, giúp thuật toán nội suy và tối ưu hóa ma trận camera hoạt động hiệu quả nhất. Việc duy trì sự cân đối giữa kích thước ô và số lượng góc như thế này giúp camera dễ dàng nhận diện và phân biệt các điểm góc ngay cả khi bàn cờ bị nghiêng hoặc đặt ở khoảng cách xa so với ống kính.

Mục tiêu của calib camera là xác định các thông số quan hệ giữa tọa độ thực và tọa độ ảnh. Các thông số cần được xác định trong quá trình calib camera gồm 2 phần:

- Thông số nội của camera: phụ thuộc vào cấu tạo bên trong của từng loại camera và thể hiện mối quan hệ giữa tọa độ ảnh và tọa độ camera.

- Thông số ngoại của camera là kết quả của phép chuyển đổi hình học giữa tọa độ thực và tọa độ camera

Trong xử lý ảnh, camera đóng vai trò ghi lại đối tượng trong không gian thực và thể hiện lại vị trí, hình dạng của đối tượng đó trong mặt phẳng ảnh. Vì thế, mô hình pinhole camera như được sử dụng để chuyển đổi giữa tọa độ ảnh sang tọa độ thực của đối tượng.

Hình 2.44

Trong đó:

- N là một điểm trong không gian, có tọa độ (XW, YW, W) trong hệ tọa độ thực, còn trong hệ tọa độ camera điểm N có tọa độ là (X, Y, Z).
- S(uS, vS) là hình chiếu của góc tọa độ O của camera lên mặt phẳng ảnh I.
- P(uP, vP) là ảnh của điểm N trong mặt phẳng ảnh I.
- f là tiêu cự của camera.

Hệ tọa độ thực và hệ tọa độ camera đều là các hệ tọa độ trong không gian 3 chiều, nên việc chuyển đổi qua lại giữa 2 hệ tọa độ này thực chất là thực hiện tổ hợp phép tịnh tiến và quay một trong 2 hệ tọa độ đến vị trí trùng với hệ tọa độ còn lại. Phương trình (3.1) thể hiện mối quan hệ giữa tọa độ điểm N trong 2 hệ tọa độ:

# 4.1.3 Thu thập hình ảnh

# 4.1.4 Lưu đồ thuật toán xác định tọa độ

# 4.2 Xây dựng bộ điều khiển chính

# 4.2.1 Phần mềm lập trình

# 4.2.2 Giao thức truyền nhận

# 4.2.3 Xác định Home cho Robot

# 4.2.4 Thiết kế giao diện điều khiển

# 4.2.5 Xây dựng thuật toán điều khiển cho bậc tự do thứ 4

# 4.2.6 Lưu đồ giải thuật bộ điều khiển

# CHƯƠNG 5 ĐÁNH GIÁ HỆ THỐNG VÀ THU THẬP KẾT QUẢ

# 5.1 Kiểm nghiệm

# 5.1.1 Kiểm tả độ chính xác cấu trúc cơ khí

# 5.1.2 Đánh giá độ lặp lại của Robot

# 5.1.3 Kiểm tra tọa độ chính xác của hệ thống

# 5.2 Bài toán sắp xếp vật tĩnh

# 5.2.1 Sắp xếp vật tĩnh hình tròn

# 5.2.2 Sắp xếp vật tĩnh cho bậc tự do thứ 4

# 5.3 Bìa toán sắp xếp vật động sử dụng bậc tự do thứ 4

# 5.3.1 Lựa chọn tốc độ bàn xoay

# 5.3.2 Xác định tọa độ vật thể

# 5.3.3 Góc xoay bậc thứ 4

# 5.3.4 Tốc độ xử lý

# 5.3.5 Kết quả điều khiển

# CHƯƠNG 6 KẾT LUẬN TỔNG QUÁT VÀ HƯỚNG PHÁT TRIỂN ĐỀ TÀI

# 6.1 Kết luận tổng quát

# 6.2 Hướng phát triển trong tương lai

# TÀI LIỆU THAM KHẢO

PHỤ LỤC

GVHD: ThS. Trần Sĩ Lâm 2

SVTH: Đặng Rui Bi 2 MSSV: CNCD2211024

PHỤ LỤC

Thiết kế, chế tạo Robot song song Delta ứng dụng trong học tập và nghiên cứu

CHƯƠNG 1: TỔNG QUAN VỀ ĐỀ TÀI

CHƯƠNG 2: MÔ HÌNH HÓA HỆ THỐNG CƠ KHÍ

CHƯƠNG 3: NỘI DUNG

CHƯƠNG 4: XÂY DỰNG THUẬT TOÁN ĐIỀU KHIỂN CHO HỆ THỐNG

CHUONG 5: ĐÁNH GIÁ HỆ THỐNG VÀ THU THẬP KẾT QUẢ

CHUONG 6: KẾT LUẬN TỔNG QUÁT VÀ HƯỚNG PHÁT TRIỂN ĐỀ TÀI

TÀI LIỆU THAM KHẢO

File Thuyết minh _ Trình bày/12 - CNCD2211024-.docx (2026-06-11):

TRƯỜNG ĐẠI HỌC KỸ THUẬT - CÔNG NGHỆ CẦN THƠ

KHOA KỸ THUẬT CƠ KHÍ (cỡ chữ 13)


ĐỀ CƯƠNG CHI TIẾT ĐỒ ÁN TỐT NGHIỆP ĐẠI HỌC

ĐỀ TÀI

THIẾT KẾ CHẾ TẠO ROBOT SONG SONG DELTA

PHỤC VỤ CHO HỌC TẬP VÀ NGHIÊN CỨU

GIẢNG VIÊN HƯỚNG DẪN | SINH VIÊN THỰC HIỆN
ThS. Trần Sĩ Lâm | Họ và tên sinh viên: Đặng Rui Bi MSSV: CNCD2211024 Ngành: Cơ điện tử.

Cần thơ, Tháng … năm 2026

TRƯỜNG ĐẠI HỌC KỸ THUẬT- CÔNG NGHỆ CẦN THƠ

KHOA KỸ THUẬT CƠ KHÍ (cỡ chữ 13)

ĐỀ CƯƠNG CHI TIẾT ĐỒ ÁN TỐT NGHIỆP ĐẠI HỌC

ĐỀ TÀI

THIẾT KẾ CHẾ TẠO ROBOT SONG SONG DELTA

PHỤC VỤ CHO HỌC TẬP VÀ NGHIÊN CỨU

GIẢNG VIÊN HƯỚNG DẪN | SINH VIÊN THỰC HIỆN
ThS. Trần Sĩ Lâm | Họ và tên sinh viên: Đặng Rui Bi MSSV: CNCD2211024 Ngành: Cơ điện tử.

Cần thơ, Tháng … năm 202

1. Đặt vấn đề

1.1 Vấn đề khoa học

Trong thời kỳ phát triển công nghiệp hiện nay, ngành công nghiệp robot đóng vai trò vô cùng quan trọng, trở thành động lực phát triển của nhiều lĩnh vực sản xuất, y tế, dịch vụ, …. Robot không những giúp tự động hóa các quy trình, nâng cao năng suất mà còn giảm thiểu rủi ro cho con người trong các môi trường nguy hiểm.

Trong số các loại robot công nghiệp, robot song song nổi bật với những ưu điểm vượt trội về độ cứng vững cao, độ chính xác và tốc độ làm việc nhanh chóng. Đặc biệt, robot Delta, với cấu trúc động học song song độc đáo, đã chứng minh được hiệu quả vượt trội trong các ứng dụng đòi hỏi tốc độ cao như phân loại, đóng gói, lắp ráp linh kiện điện tử và phẫu thuật. Khả năng di chuyển nhanh và chính xác của robot Delta đã mở ra nhiều tiềm năng ứng dụng mới, góp phần nâng cao hiệu suất và tối ưu hóa quy trình sản xuất.

Với mong muốn tìm hiểu sâu hơn về lĩnh vực robot học nói chung và robot song song Delta nói riêng, cũng như ứng dụng những kiến thức đã học vào thực tiễn, tôi đã lựa chọn đề tài "Thiết kế, chế tạo robot song song Delta phục vụ cho học tập và nghiên cứu" làm đề tài báo cáo tốt nghiệp của mình. Đề tài này không chỉ giúp tôi củng cố kiến thức về động học, động lực học và điều khiển robot, mà còn trang bị những kỹ năng thực tế trong việc xây dựng và vận hành một hệ thống robot hoàn chỉnh.

1.2 Giả thuyết khoa học

Nếu xây dựng một hệ thống điều khiển robot song song Delta dựa trên cấu trúc phân tầng Master-Slave – trong đó máy tính đóng vai trò "Master" thực hiện thuật toán xử lý ảnh thời gian thực (như nhận diện màu sắc/hình dáng bằng OpenCV) và tính toán động học nghịch, kết hợp truyền thông bộ dữ liệu điều khiển xuống vi điều khiển "Slave" để điều phối các động cơ bước (Stepper Motor) truyền động qua cơ cấu khâu khớp song song – thì hệ thống sẽ đạt được các kết quả sau:

Tối ưu hóa năng lực tính toán và tốc độ đáp ứng: Việc tách biệt nhiệm vụ xử lý ảnh (nặng về thuật toán) trên máy tính và nhiệm vụ điều khiển xung/chiều (nặng về tính thời gian thực) trên vi điều khiển sẽ giảm tải tối đa cho phần cứng nhúng. Điều này cho phép robot thực hiện chu trình gắp-thả (Pick and Place) hoặc bám mục tiêu liên tục với tần số cao mà không gặp hiện tượng trễ hay mất bước.

Đảm bảo độ chính xác động học: Thông qua việc thiết lập mô hình toán học động học nghịch chính xác kết hợp với thuật toán nội suy quỹ đạo mượt mà, robot Delta có thể chuyển đổi tọa độ pixel từ camera thành góc quay của các cánh tay đòn một cách chính xác, sai số vị trí ở khâu chấp hành cuối (End-effector) nằm trong phạm vi dung sai cho phép của các mô hình công nghiệp quy mô nhỏ.

Nâng cao tính linh hoạt và độ ổn định nhờ cấu trúc song song: Khác với robot chuỗi hở, cấu trúc 3 cánh tay song song đồng dạng của robot Delta giúp phân đều tải trọng lên các motor cố định ở khung trên. Nhờ đó, việc tính toán và tinh chỉnh các tham số động lực học sẽ giúp hệ thống triệt tiêu rung động, vận hành ổn định ở gia tốc lớn mà vẫn giữ được độ cứng vững cơ khí cao.

1.3 Lý do chọn đề tài

Ứng dụng: Robot Delta là lựa chọn hàng đầu cho các ngành công nghiệp đòi hỏi tốc độ và độ chính xác cao trong việc xử lý các vật thể nhỏ và nhẹ:

- Phân loại và đóng gói: Trong ngành thực phẩm (kẹo, bánh quy), dược phẩm (viên thuốc), điện tử (linh kiện nhỏ).
- Lắp ráp linh kiện điện tử: Lắp ráp các chi tiết nhỏ, ví dụ như chip lên bảng mạch.
- Chọn và đặt (Pick-and-place): Di chuyển nhanh các vật thể từ vị trí này sang vị trí khác trên dây chuyền sản xuất.
- Kiểm tra sản phẩm: Di chuyển cảm biến hoặc camera để kiểm tra sản phẩm trên dây chuyền với tốc độ cao.
- Ứng dụng y tế: Một số biến thể được dùng trong phẫu thuật hoặc các thiết bị y tế đòi hỏi độ chính xác cao.

Robot Delta là một đối tượng nghiên cứu điển hình trong lĩnh vực cơ học nhờ cấu trúc động học song song (parallel kinematics) độc đáo. Khác với các robot dạng chuỗi hở thông thường, Robot Delta sử dụng ba cánh tay cơ học được nối từ một đế cố định đến một mâm chuyển động (end-effector). Trong nghiên cứu, việc phân tích bài toán động học thuận và nghịch của Delta đòi hỏi các mô hình toán học phức tạp để xác định vị trí chính xác của mâm động dựa trên góc quay của các động cơ servo, stepper. Các nhà nghiên cứu thường tập trung vào việc tối ưu hóa "vùng làm việc" (workspace) và phân tích các điểm kỳ dị (singularities) để đảm bảo robot vận hành ổn định. Nhờ cấu tạo nhẹ và độ cứng vững cao, đây là mô hình lý tưởng để thử nghiệm các thiết kế cơ khí chính xác, nơi mà sai số tích lũy từ các khớp nối được giảm thiểu tối đa so với robot truyền thống.

Trong môi trường học thuật, robot Delta đóng vai trò là nền tảng quan trọng để triển khai và kiểm chứng các thuật toán điều khiển tốc độ cao. Do đặc thù được thiết kế cho các tác vụ "Pick and Place" (gắp và đặt), việc lập trình quỹ đạo (trajectory planning) cho Delta yêu cầu khả năng xử lý thời gian thực cực kỳ nhạy bén để đạt được gia tốc lớn mà không gây rung lắc. Sinh viên và nghiên cứu sinh thường ứng dụng các bộ điều khiển PID nâng cao, điều khiển mờ (Fuzzy Logic) hoặc mạng nơ-ron để tối ưu hóa chuyển động. Bên cạnh đó, việc tích hợp hệ thống thị giác máy tính (Computer Vision) vào robot Delta là một hướng nghiên cứu phổ biến, cho phép robot nhận diện, phân loại và bám sát đối tượng trong không gian ba chiều với độ trễ thấp. Đây chính là bước đệm quan trọng để phát triển các hệ thống sản xuất thông minh và tự động hóa linh hoạt trong tương lai.

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

1.4 Tính cấp thiết của đề tài

Xuất phát từ thực tiễn đó, Robot song song Delta nổi lên như một giải pháp tối ưu nhờ cấu trúc cơ khí đặc biệt: toàn bộ các động cơ truyền động được đặt cố định tại đế nguồn, giúp giảm tối đa khối lượng các khâu động. Đặc tính này cho phép robot Delta đạt được gia tốc cực kỳ lớn và tốc độ vận hành vượt trội, trở thành "trục xương sống" trong các tác vụ gắp-thả (Pick and Place) tốc độ cao.

Tuy nhiên, nếu chỉ vận hành theo các chu trình lặp đi lặp lại được lập trình sẵn (Blind Robot), robot sẽ hoàn toàn mất đi tính linh hoạt khi môi trường thay đổi (ví dụ: sản phẩm trên băng tải bị lệch hướng, thay đổi hình dáng hoặc màu sắc). Do đó, việc tích hợp hệ thống thị giác máy tính (Computer Vision) đóng vai trò như "đôi mắt", cho phép robot nhận diện, định vị tọa độ, phân loại biên dạng và màu sắc của đối tượng trong thời gian thực. Sự kết hợp giữa năng lực tính toán xử lý ảnh trên máy tính (Master) và khả năng bám quỹ đạo chính xác của vi điều khiển (Slave) tạo nên một hệ sinh thái Cơ điện tử thông minh, thích ứng cao với sự đa dạng của sản phẩm trên dây chuyền.

Tại Việt Nam, nhu cầu chuyển đổi số và tự động hóa trong các nhà máy sản xuất vừa và nhỏ đang tăng trưởng mạnh mẽ, nhưng chi phí để nhập khẩu và bảo trì các hệ thống robot Delta tích hợp thị giác máy từ nước ngoài (như ABB, Fanuc, Delta Electronics) là cực kỳ đắt đỏ. Việc nghiên cứu, thiết kế, chế tạo và làm chủ thuật toán điều khiển robot song song Delta kết hợp xử lý ảnh ở quy mô phòng thí nghiệm không chỉ mang ý nghĩa thực tiễn trong việc tối ưu hóa chi phí, mà còn là bước đi cấp thiết giúp sinh viên ngành Cơ điện tử tiếp cận sâu sắc giữa lý thuyết điều khiển (động học nghịch, nội suy quỹ đạo) và thực tiễn công nghệ (xử lý ảnh thời gian thực, truyền thông Master-Slave).

Chính vì những lý do trên, đề tài "Nghiên cứu, thiết kế và chế tạo hệ thống Robot song song Delta" là hoàn toàn mang tính cấp thiết, có ý nghĩa khoa học và giá trị ứng dụng thực tiễn cao trong bối cảnh hiện nay.

2. Mục đính và mục tiêu nghiên cứu

2.1 Mục đích

Nghiên cứu, thiết kế và chế tạo thành công một hệ thống Robot song song Delta 4 bậc tự do hoàn chỉnh, có khả năng nhận diện và phân loại vật thể bằng thị giác máy tính, phục vụ làm mô hình trực quan cho việc học tập, nghiên cứu và phát triển thuật toán điều khiển tại Trường Đại học Kỹ thuật - Công nghệ Cần Thơ.

2.2 Mục tiêu

- Xây dựng được mô hình toán học: Phân tích và giải quyết bài toán động học thuận và động học nghịch cho Robot Delta 4 bậc tự do.
- Thiết kế và chế tạo phần cứng: Thiết kế mô hình 3D (trên Inventor), lựa chọn vật liệu, tính toán truyền động và gia công lắp ráp hoàn thiện mô hình cơ khí đảm bảo đủ độ chính xác trong quá trình điều khiển.
- Phát triển hệ thống điều khiển và xử lý ảnh: Thiết lập thuật toán nhận diện vật thể (hình dáng, màu sắc) ứng dụng Computer Vision và truyền thông dữ liệu xuống vi điều khiển. Xử lý thị giác máy với sai lệch cho phép ±2 mm
- Thuật toán quy hoạch quỹ đạo được đề xuất giúp robot chuyển động liên tục, giảm chấn và gắp thả chính xác theo các quỹ đạo hình học định sẵn với sai số không quá 10%. Hệ thống được thiết kế để tối ưu hóa cho bài toán phân loại với vận tốc quỹ đạo đạt 0.8 - 1.0 m/s và gia tốc đạt 5 m/s².
- Xây dựng bộ điều khiển PID dựa trên phương pháp thử sai nhằm tối ưu sai số mong muốn.
- Xây dựng giao diện người dùng (GUI): Tạo giao diện điều khiển và giám sát trực quan trên máy tính (Laptop) để người dùng dễ dàng thao tác và đánh giá hệ thống. Tích hợp nhiều chức năng cùng với khả năng giám xác hệ thống chính xác.

3. Lược khảo tài liệu

Trong quá trình thực hiện đồ án, đề tài kế thừa và tham khảo các hướng nghiên cứu tiêu biểu sau:

Lê Thể Truyền và cộng sự (Đại học Công nghiệp Thực phẩm TP.HCM) - "Thiết kế các kích thước của rô-bốt delta dựa trên không gian làm việc": Nghiên cứu này cung cấp cơ sở vững chắc về phương pháp tối ưu hóa kích thước các khâu cơ khí để đạt được không gian làm việc (workspace) lớn nhất mà không rơi vào các điểm kỳ dị (singularities).

Phan Gia Huy (Đại học Bách Khoa – ĐHQG Tp. HCM) - "Thiết kế, chế tạo Robot song song delta ứng dụng trong phân loại sữa có xử lý ảnh": Đề tài này đưa ra các nền tảng cơ bản trong việc tích hợp camera vào không gian làm việc của robot và thuật toán phân loại đối tượng cơ bản.

Nhận xét: Đa phần các nghiên cứu trong nước dành cho sinh viên hiện nay chỉ dừng lại ở cấu hình Robot Delta 3 bậc tự do (chỉ tịnh tiến XYZ). Đề tài này của em sẽ phát triển thêm bậc tự do thứ 4 (xoay quanh trục Z tại mâm động) để tăng tính linh hoạt khi gắp vật bị xoay nghiêng, đồng thời xây dựng một giao diện phần mềm hoàn thiện hướng tới mục tiêu dùng làm học cụ chuẩn mực cho nhà trường.

4. Đối tượng và khách thể nghiên cứu

4.1. Đối tượng nghiên cứu

- Mô hình vật lý của Robot song song Delta 4 bậc tự do.
- Các bài toán động học, quy hoạch quỹ đạo và không gian làm việc của robot.
- Hệ thống điều khiển, phần mềm xử lý ảnh và giao diện người - máy (GUI).

4.2. Khách thể nghiên cứu

Các hệ thống robot song song tồn tại trước đó

Ứng dụng công nghệ thị giác máy tính (Computer Vision) trong lĩnh vực tự động hóa công nghiệp.

Vi điều khiển STM32 có thế mạnh điều khiển xung mượt và mạnh, với tần số 72MHz.

Camera phù hợp với khả năng xử lý vật tĩnh lẫn động tốt.

5. Phương pháp nghiên cứu

## 5.1. Phương pháp phân tích và tổng hợp lý thuyết

## Thu thập, phân tích và tổng hợp các tài liệu học thuật, giáo trình, bài báo khoa học về động học robot song song, cơ sở truyền động cơ khí.

## Nghiên cứu lý thuyết về thị giác máy tính, nhận dạng mẫu và các thuật toán nội suy quỹ đạo trong điều khiển tự động.

## 5.2. Phương pháp thực nghiệm

Xây dựng mô hình 3D và tiến hành mô phỏng (trên Matlab/Simulink và Inventor) để kiểm nghiệm không gian làm việc trước khi gia công.

Chế tạo, lắp ráp phần cứng thật và thiết lập hệ thống mạch điện.

Chạy thử nghiệm thực tế thuật toán xử lý ảnh, thuật toán điều khiển động cơ.

Đo đạc sai số thực tế so với lý thuyết để hiệu chỉnh các thông số PID và tinh chỉnh hệ thống nhằm đạt được sự ổn định cao nhất. Xây dụng các bài test cho Robot ví dụ vẽ các hình với kích thước cụ thể, sau đó đo lại kích thước bằng cách thủ công nhằm kiểm chứng độ sai lệch và xem xét phạm vi cho phép.

6. Phạm vi nghiên cứu

Phạm vi nghiên cứu của đề tài tập trung vào việc thiết kế và điều khiển mô hình robot Delta để thực hiện các nhiệm vụ đòi hỏi độ chính xác cao trong không gian ba chiều. Cụ thể, nghiên cứu giới hạn trong việc xây dựng thuật toán quy hoạch quỹ đạo để điều khiển robot thực hiện các đường nét hình học cơ bản như hình tròn, hình vuông và hình tam giác với sai số tối thiểu. Bên cạnh đó, đề tài đi sâu vào việc tích hợp hệ thống xử lý ảnh để nhận diện và phân loại vật thể dựa trên đặc trưng màu sắc và hình dạng, từ đó tối ưu hóa khả năng tương tác của robot trong các ứng dụng phân loại tự động. Các thử nghiệm và đánh giá được thực hiện trong môi trường phòng thí nghiệm nhằm kiểm chứng sự ổn định của hệ thống điều khiển và độ chính xác của các thuật toán động học đã thiết lập

7. Kế hoạch thực hiện

- Nghiên cứu, Thiết kế và chế tạo mô hình: 5 tuần (20/04/2026 đến 25/05/2026).
- Thực hiện mô hình và chạy thử: 6 tuần (01/06/2026 đến 10/07/2026).
- Đánh giá và sửa lỗi: 4 tuần (11/07/2026 đến 09/08/2026).
- Cải tiến phát triển: 2 tuần (10/08/2026 đến 24/08/2026).
- Viết bài báo cáo và hiệu chỉnh các thông số: 4 tuần (25/08/2026 đến 22/09/2026).

8. Tài liệu tham khảo (xem phụ lục tài liệu tham khảo)

# PHỤ LỤC: TÀI LIỆU THAM KHẢO

[1] - https://new.abb.com/products/robotics/robots/delta-robots/irb-360

[2] - https://www.packagingstrategies.com/articles/87931-omrons-sysmac-delta-robotseries-increases-production-in-high-speed-pick-place-packaging

[3] - https://www.daincube.com/product/robot-controller/dtp7h-corecon

[4] - https://www.smcworld.com/products/subject/en-jp/newgen_space/vacuum/zp3

[5] - https://www.smcworld.com/assets/manual/en-jp/files/ZK2-E.pdf

[6] - https://www.baslerweb.com/en/products/cameras/area-scan-cameras/ace/aca720-520um

[7] - https://www.raspberrypi.com/products/raspberry-pi-4-model-b

[8] David G. Lowe (2004). Distinctive Image Features from Scale-Invariant Keypoints. International Journal of Computer Vision 60, 2, pp. 91-110.

[9] Ethan Rublee et al. (2011). ORB: an efficient alternative to SIFT a nd SUFT. IEEE International Conference on Computer Vision, pp. 2564-2571.

[10] Deward Rosten, Tom Drummond (2006). Machine learning for high-speed corner detection. Department of Engineering, Cambrigde University, UK.

[11] Michaeal Calonder et al. (2010). BRIEF: Binary Robust Independent Elemantary Features. CVLav, EPFL, Lausanse, Switzerland.

[12] Lung-Wen Tsai (1999). Robot Analysis. Department of Mechanical Engineering and Institute for Systems Research, University of Maryland.

[13] Đinh Anh Thắng (2021), Nghiên cứu và phát triển robot Delta 3 bậc tự do ứng dụng trong lắp ráp vật tĩnh. Luận văn đại học, Đại học Bách Khoa Tp.HCM.

[14] - https://www.daincube.com/product/safety-controller/drsc

SVTH: Nguyễn Văn B 77

Đề cương chi tiết Đồ án tốt nghiệp

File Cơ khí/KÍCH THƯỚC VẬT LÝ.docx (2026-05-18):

KÍCH THƯỚC VẬT LÝ

R | Bán kính khâu đế | 100
r | Bán kính khâu di động | 50
a | Chiều dài Link 1 | 130
b | Chiều dài Link 2 | 398
| | (mm)

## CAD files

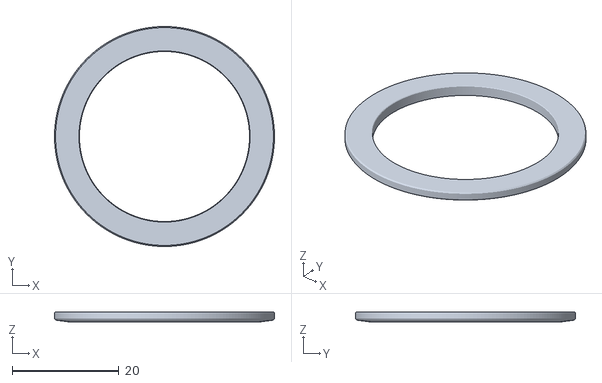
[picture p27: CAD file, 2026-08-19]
Thiết kế/Delta Part/GT2_60T/stl step igs/60pitch pulley GT2 6mm ASSEMBLY - Gear 60pitch part02-2.STL
41.2 x 41.2 x 1.92

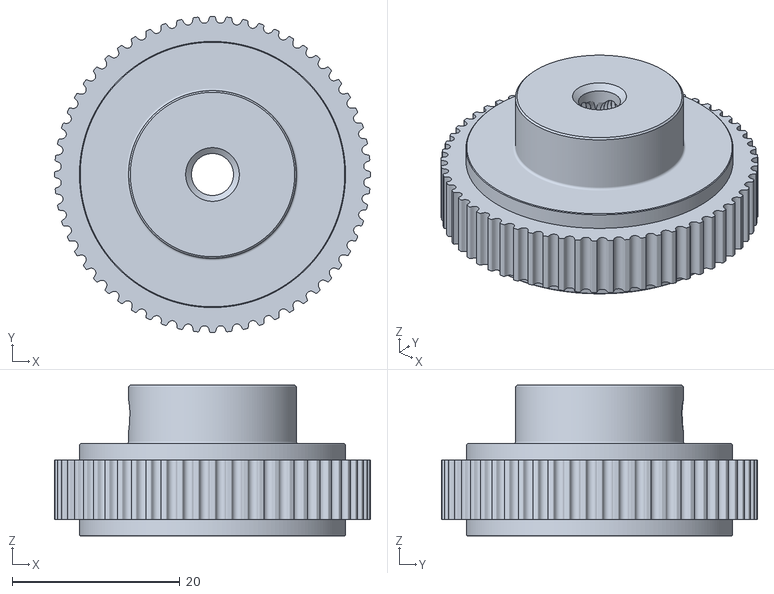
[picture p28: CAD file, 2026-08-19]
Thiết kế/Delta Part/GT2_60T/stl step igs/60pitch pulley GT2 6mm ASSEMBLY - Pulley part01 GT2 6mm-1.STL
37.7 x 37.7 x 18.0

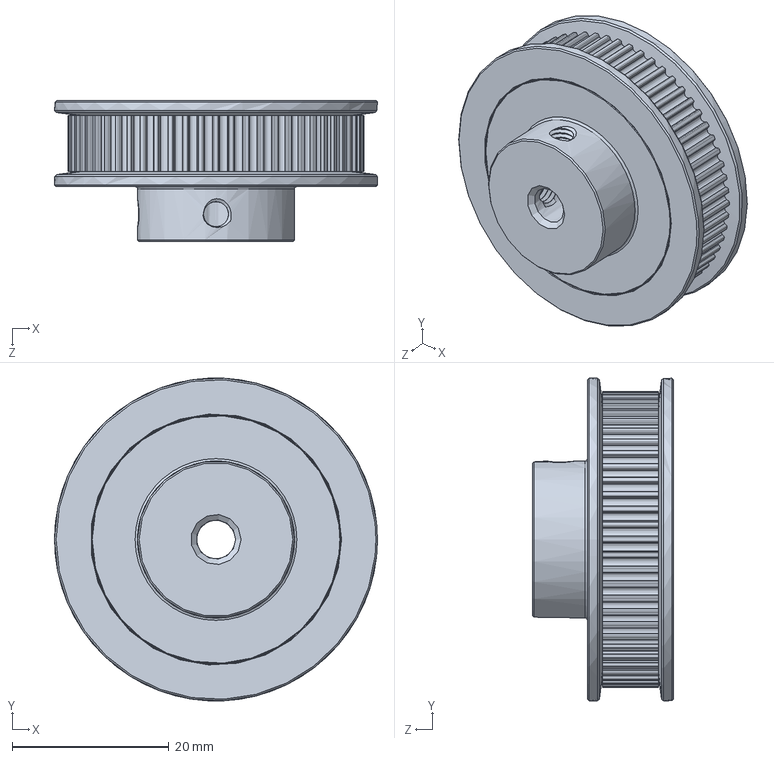
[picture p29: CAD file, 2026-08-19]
Thiết kế/Delta Part/GT2_60T/stl step igs/60pitch pulley GT2 6mm ASSEMBLY PART.SLDPRT
41.2 x 41.1 x 18.0 mm

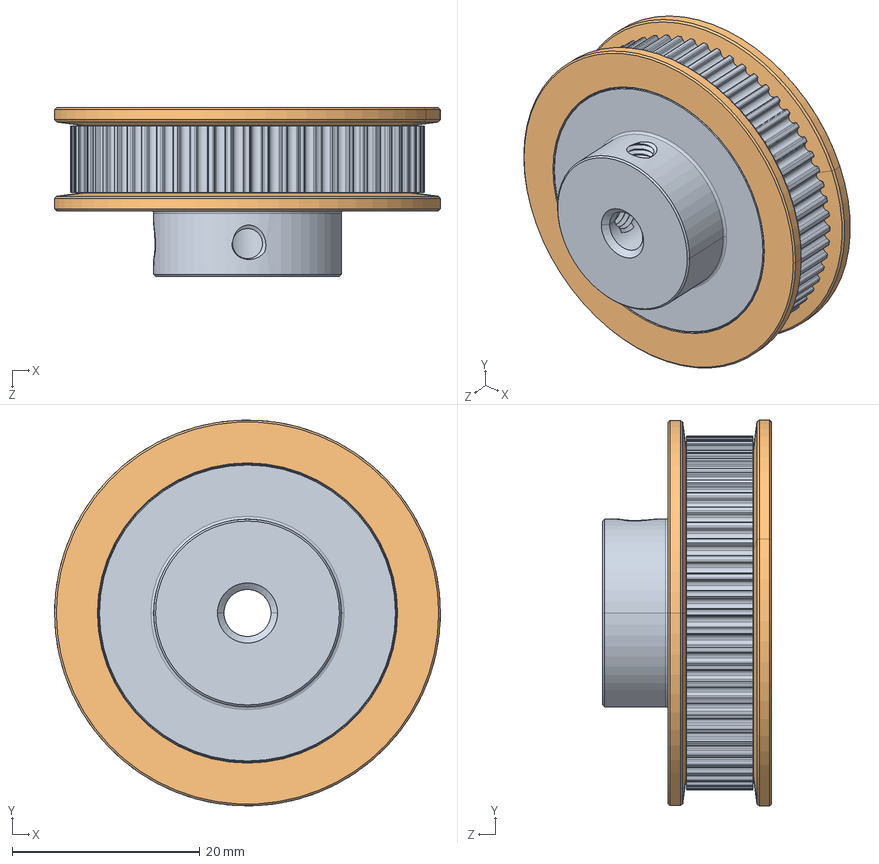
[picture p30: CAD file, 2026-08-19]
Thiết kế/Delta Part/GT2_60T/stl step igs/60pitch pulley GT2 6mm ASSEMBLY.STEP
41.1 x 41.1 x 18.0 mm
Pulley part01 GT2 6mm
Gear 60pitch part02 x 2

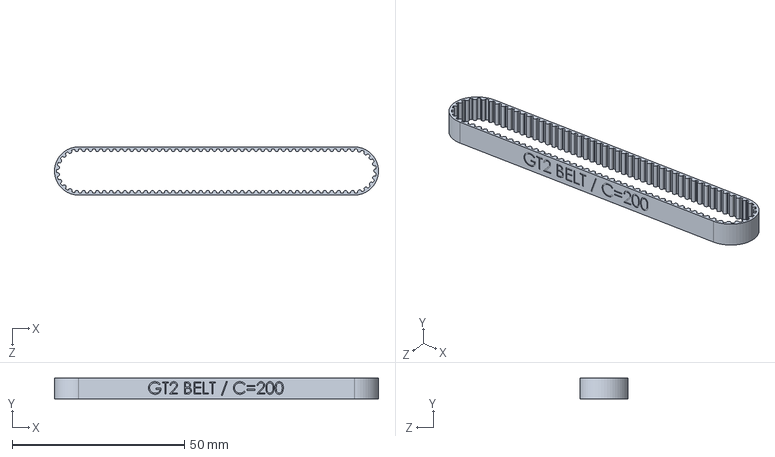
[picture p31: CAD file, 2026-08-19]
Thiết kế/Delta Part/Belt/gt2 belt C200.STEP
94.0 x 6.00 x 14.0 mm

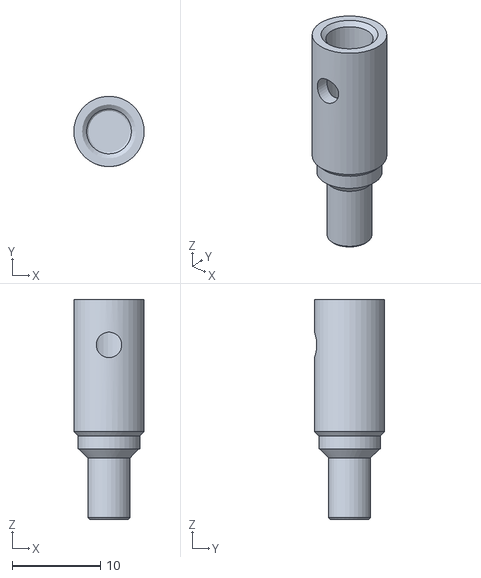
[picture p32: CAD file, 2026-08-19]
Thiết kế/Delta Part/Tool/khới nối cứng.stl
8.00 x 7.99 x 25.0

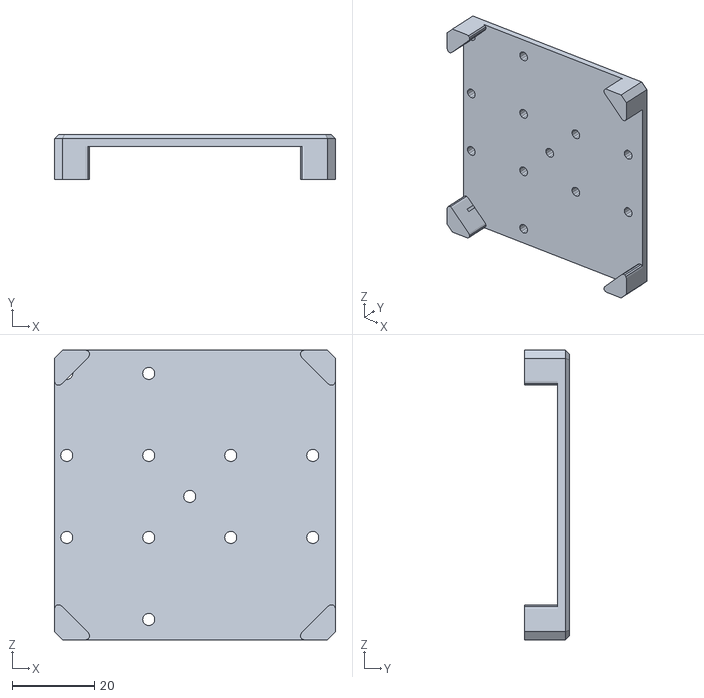
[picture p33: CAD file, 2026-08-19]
Thiết kế/Tool_STL/Repick.stl
68.5 x 11.0 x 70.7

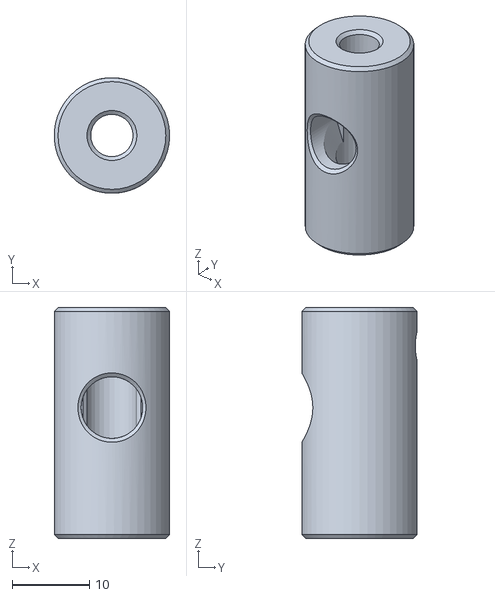
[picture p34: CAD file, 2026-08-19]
Thiết kế/Tool_STL/nối bậc 4.stl
15.0 x 15.0 x 30.0

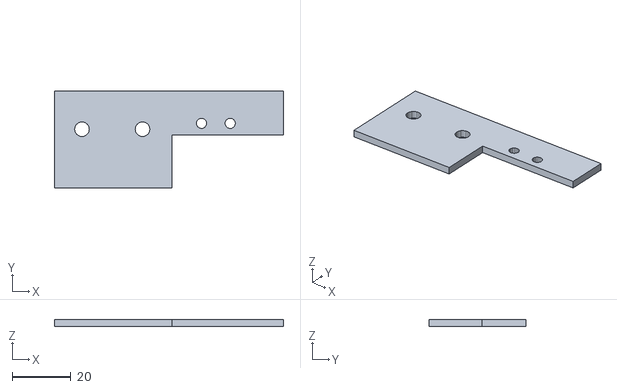
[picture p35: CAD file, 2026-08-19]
Thiết kế/Tool_STL/Part1.stl
78.0 x 33.0 x 2.50

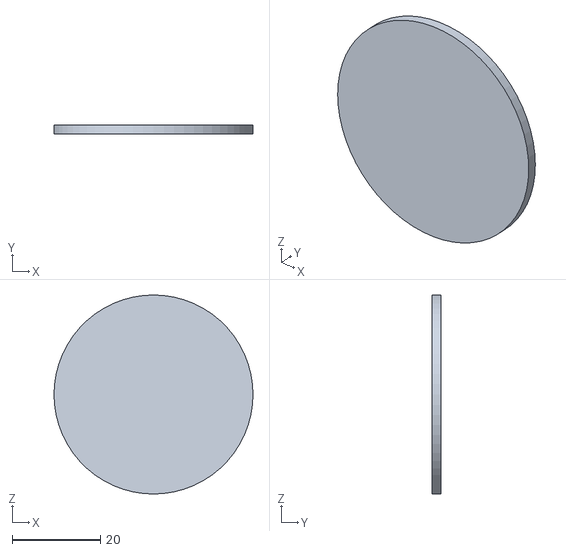
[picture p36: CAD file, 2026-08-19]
Thiết kế/Tool_STL/45.stl
45.0 x 2.00 x 45.0

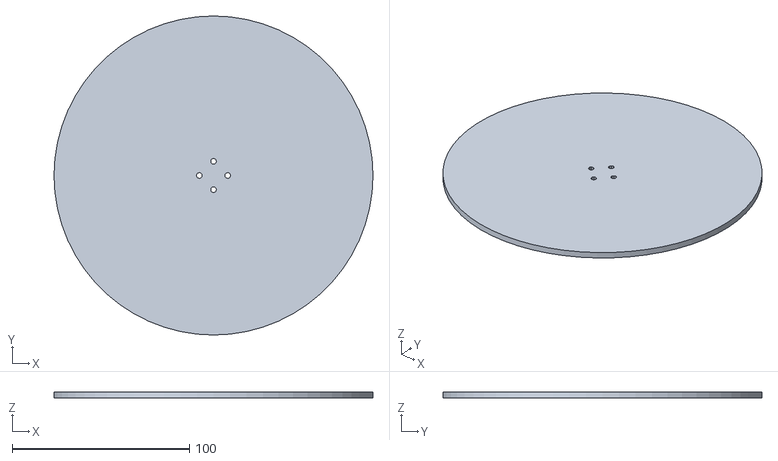
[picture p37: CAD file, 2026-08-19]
Thiết kế/Tool_STL/bàn xoay.stl
180.0 x 180.0 x 3.50

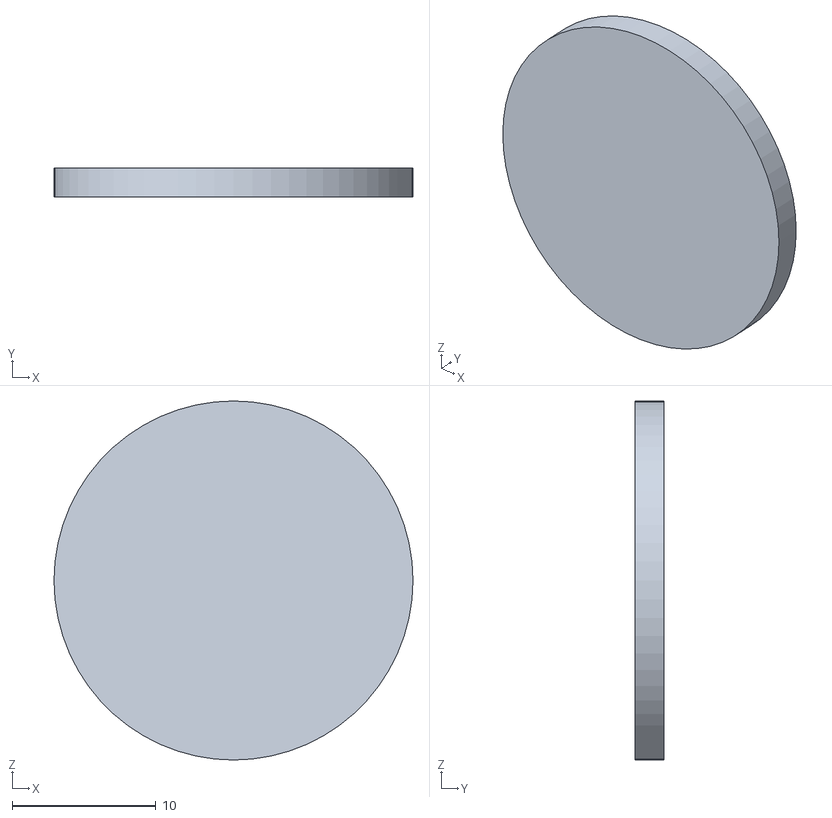
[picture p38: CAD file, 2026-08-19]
Thiết kế/Tool_STL/25.stl
25.0 x 2.00 x 25.0

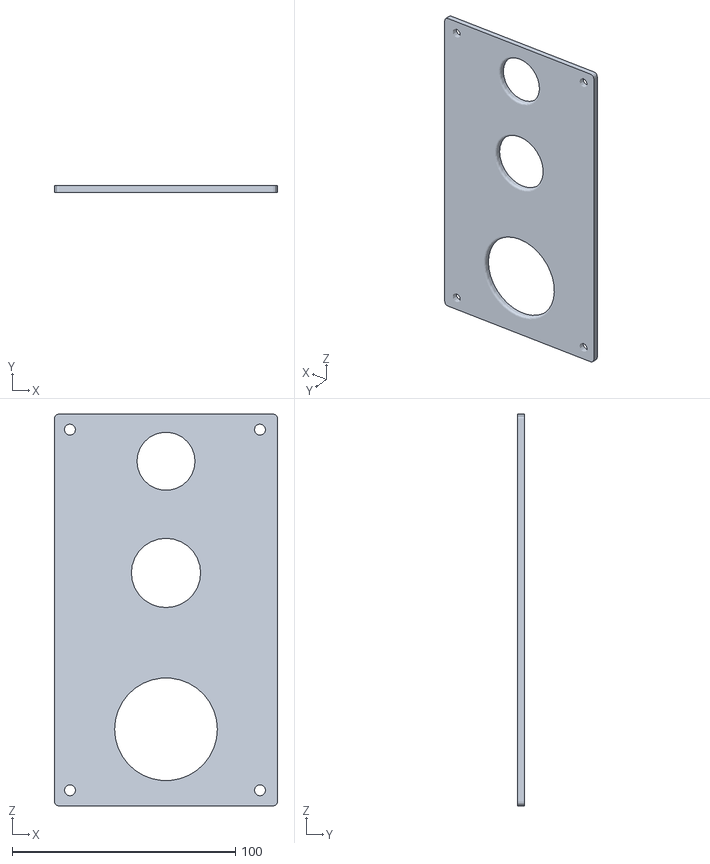
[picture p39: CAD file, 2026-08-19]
Thiết kế/Tool_STL/Circle_Color.stl
100.0 x 3.00 x 175.5

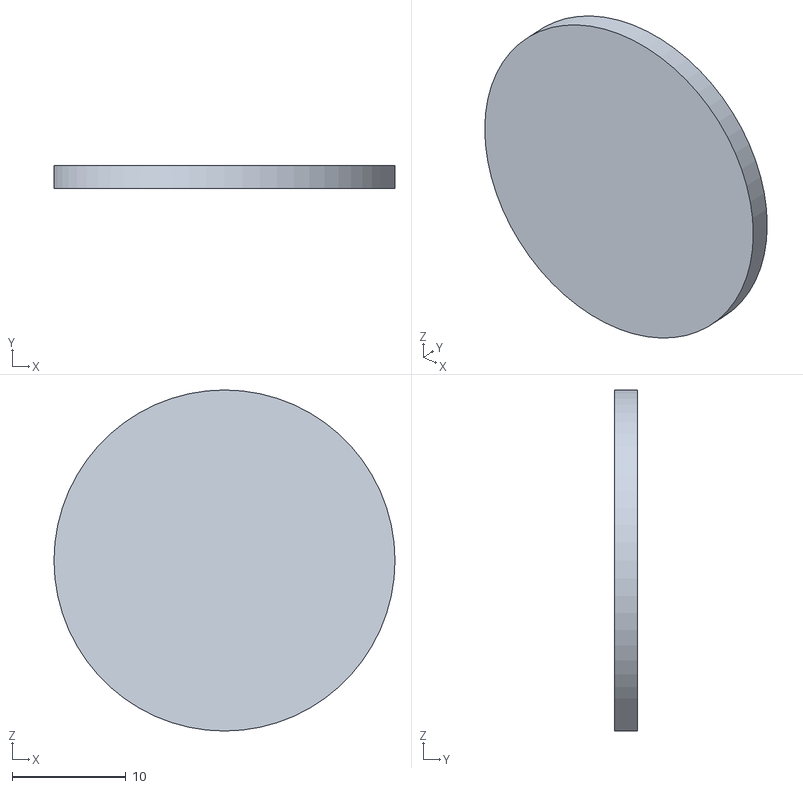
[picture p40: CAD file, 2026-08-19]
Thiết kế/Tool_STL/30.stl
30.0 x 2.00 x 30.0

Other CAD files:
Thiết kế/Delta Part/GT2_60T/stl step igs/60pitch pulley GT2 6mm ASSEMBLY - Gear 60pitch part02-3.STL
Thiết kế/Delta Part/GT2_60T/stl step igs/Pulley part01 GT2 6mm.STEP
Thiết kế/Delta Part/GT2_60T/stl step igs/Gear 60pitch part02.STEP
Thiết kế/Tool_STL/4_DOF_2.stl
Thiết kế/Base_E_buff.ipt
Thiết kế/Delta Part/Assembly2.iam
Thiết kế/Delta Part/Base_E_buffer.ipt
Thiết kế/Delta Part/Belt/gt2 belt C200.SLDPRT
Thiết kế/Delta Part/Belt/gt2 belt C200/gt2 belt C200.ipt
Thiết kế/Delta Part/Delta_Robot.iam
Thiết kế/Delta Part/GT2_20T.ipt
Thiết kế/Delta Part/GT2_60.ipt
Thiết kế/Delta Part/GT2_60T/60pitch pulley GT2 6mm ASSEMBLY.SLDASM
Thiết kế/Delta Part/GT2_60T/Gear 60pitch part02.SLDPRT
Thiết kế/Delta Part/GT2_60T/Pulley part01 GT2 6mm.SLDPRT
Thiết kế/Delta Part/GT2_60T/stl step igs/60pitch pulley GT2 6mm ASSEMBLY PART.IGS
Thiết kế/Delta Part/GT2_60T/stl step igs/Gear 60pitch part02.IGS
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

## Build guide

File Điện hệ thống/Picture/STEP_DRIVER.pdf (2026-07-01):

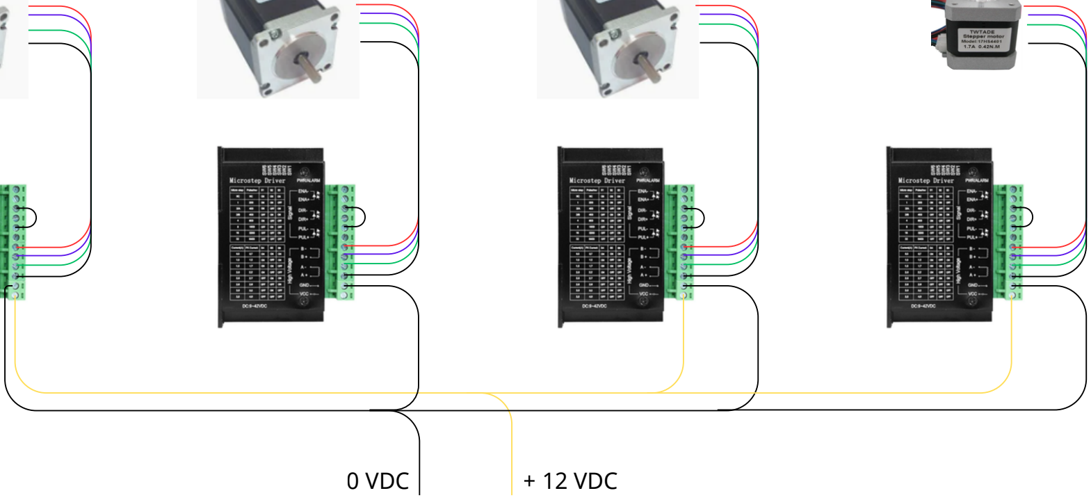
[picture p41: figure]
0 VDC; + 12 VDC

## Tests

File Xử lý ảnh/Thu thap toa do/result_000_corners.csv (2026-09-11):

corner_index | col | row | pixel_x | pixel_y | x_px | y_px | x_mm | y_mm
0 | 0 | 0 | 265.567 | 57.188 | -54.433 | 182.812 | 48.751 | 40.636
1 | 1 | 0 | 290.587 | 73.365 | -29.413 | 166.635 | 38.751 | 40.636
2 | 2 | 0 | 315.604 | 89.824 | -4.396 | 150.176 | 28.751 | 40.636
3 | 3 | 0 | 340.739 | 106.109 | 20.739 | 133.891 | 18.751 | 40.636
4 | 4 | 0 | 366.181 | 122.849 | 46.181 | 117.151 | 8.751 | 40.636
5 | 5 | 0 | 391.555 | 139.347 | 71.555 | 100.653 | -1.249 | 40.636
6 | 6 | 0 | 416.858 | 156.078 | 96.858 | 83.922 | -11.249 | 40.636
7 | 7 | 0 | 442.452 | 172.661 | 122.452 | 67.339 | -21.249 | 40.636
8 | 8 | 0 | 467.937 | 189.484 | 147.937 | 50.516 | -31.249 | 40.636
9 | 0 | 1 | 248.917 | 82.270 | -71.083 | 157.730 | 48.751 | 30.636
10 | 1 | 1 | 273.850 | 98.656 | -46.150 | 141.344 | 38.751 | 30.636
11 | 2 | 1 | 298.850 | 114.969 | -21.150 | 125.031 | 28.751 | 30.636
12 | 3 | 1 | 324.002 | 131.587 | 4.002 | 108.413 | 18.751 | 30.636
13 | 4 | 1 | 349.193 | 148.300 | 29.193 | 91.700 | 8.751 | 30.636
14 | 5 | 1 | 374.732 | 164.970 | 54.732 | 75.030 | -1.249 | 30.636
15 | 6 | 1 | 399.943 | 181.388 | 79.943 | 58.612 | -11.249 | 30.636
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

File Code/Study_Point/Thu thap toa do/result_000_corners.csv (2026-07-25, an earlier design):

corner_index | col | row | pixel_x | pixel_y | x_px | y_px | x_mm | y_mm
0 | 0 | 0 | 237.868 | 85.370 | -95.594 | 161.041 | 31.412 | 53.127
1 | 1 | 0 | 267.763 | 85.051 | -65.698 | 161.360 | 21.473 | 53.087
2 | 2 | 0 | 297.703 | 85.204 | -35.758 | 161.207 | 11.534 | 53.047
3 | 3 | 0 | 328.383 | 84.988 | -5.079 | 161.423 | 1.595 | 53.007
4 | 4 | 0 | 358.687 | 85.003 | 25.225 | 161.408 | -8.344 | 52.967
5 | 5 | 0 | 389.185 | 85.114 | 55.724 | 161.297 | -18.283 | 52.927
6 | 6 | 0 | 419.879 | 85.212 | 86.417 | 161.199 | -28.222 | 52.887
7 | 7 | 0 | 450.012 | 85.406 | 116.551 | 161.005 | -38.161 | 52.847
8 | 8 | 0 | 480.945 | 85.578 | 147.484 | 160.833 | -48.099 | 52.807
9 | 0 | 1 | 237.661 | 114.995 | -95.800 | 131.416 | 31.453 | 43.188
10 | 1 | 1 | 267.784 | 114.996 | -65.678 | 131.415 | 21.514 | 43.147
11 | 2 | 1 | 297.981 | 114.899 | -35.481 | 131.512 | 11.575 | 43.107
12 | 3 | 1 | 327.972 | 114.986 | -5.490 | 131.425 | 1.636 | 43.067
13 | 4 | 1 | 358.628 | 115.099 | 25.166 | 131.312 | -8.303 | 43.027
14 | 5 | 1 | 389.169 | 115.337 | 55.708 | 131.074 | -18.242 | 42.987
15 | 6 | 1 | 419.811 | 115.335 | 86.350 | 131.076 | -28.181 | 42.947
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

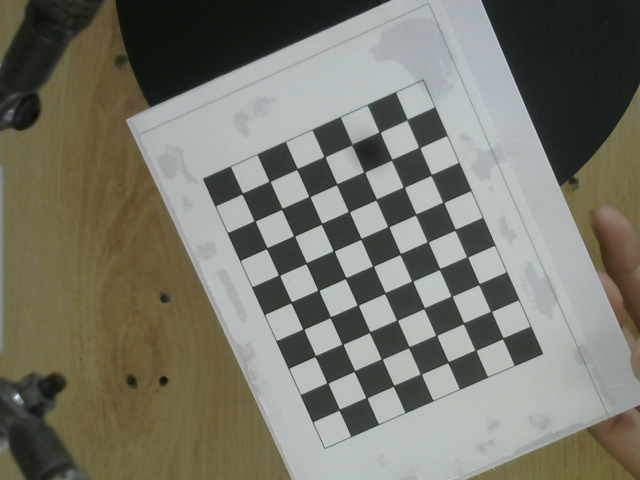
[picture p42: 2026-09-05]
Xử lý ảnh/Calibrarion_XY/images/calib_077.png

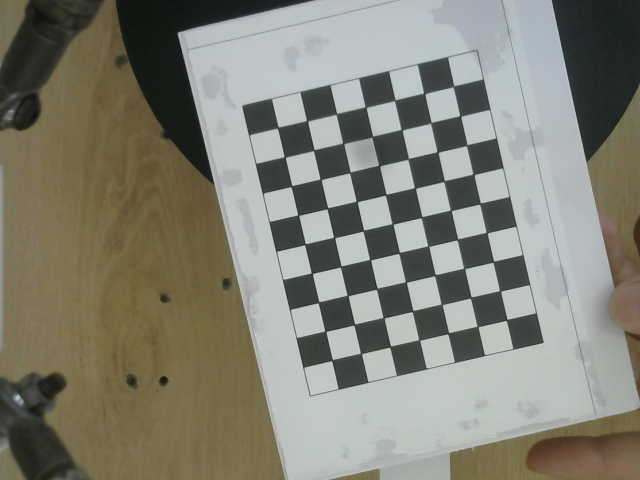
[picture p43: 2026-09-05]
Xử lý ảnh/Calibrarion_XY/images/calib_031.png

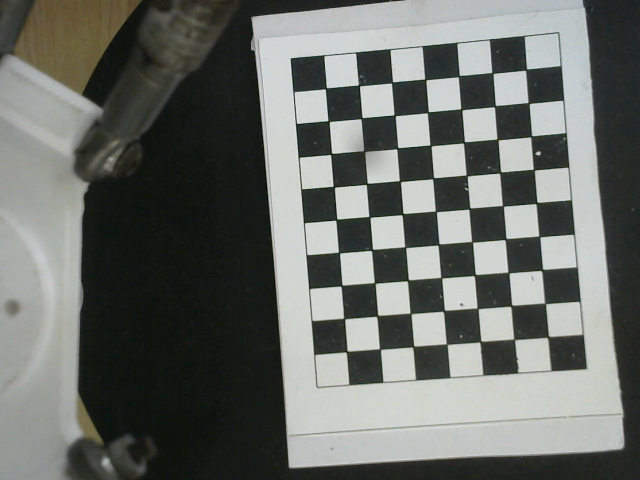
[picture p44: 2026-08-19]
Xử lý ảnh/Calibrarion_XY/images/calib_001.png

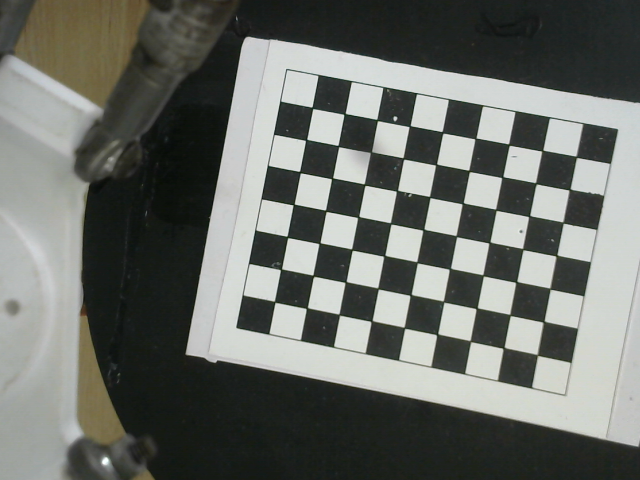
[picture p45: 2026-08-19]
Xử lý ảnh/Calibrarion_XY/images/calib_025.png

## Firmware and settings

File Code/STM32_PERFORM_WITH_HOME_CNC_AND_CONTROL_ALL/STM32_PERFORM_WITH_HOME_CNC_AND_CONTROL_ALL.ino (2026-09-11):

#include <AccelStepper.h>
#define STEP1 PA0
#define DIR1 PA1
#define STEP2 PA2
#define DIR2 PA3
#define STEP3 PA4
#define DIR3 PA5
#define SW1 PA6
#define SW2 PB0
#define SW3 PA7
#define HOME_BTN PB1
#define HOMING_SPEED_FAST 1000
#define HOMING_SPEED_SLOW 600
#define HOMING_ACCEL 200
#define RUN_SPEED 10000
#define RUN_ACCEL 8000
#define BACKOFF_STEPS 800

const float GOC_TO_STEP = 6400.0 / 360.0;
float target_theta1 = 0.0;
float target_theta2 = 0.0;
float target_theta3 = 0.0;
bool homeDone = false;

#define DEBOUNCE_BTN_MS 50
#define DEBOUNCE_SW_MS 10

static uint32_t sw1_last = 0, sw2_last = 0, sw3_last = 0;
static bool sw1_state = HIGH, sw2_state = HIGH, sw3_state = HIGH;
static uint32_t btn_last = 0;
static bool btn_state = HIGH;

AccelStepper motor1(AccelStepper::DRIVER, STEP1, DIR1);
AccelStepper motor2(AccelStepper::DRIVER, STEP2, DIR2);
AccelStepper motor3(AccelStepper::DRIVER, STEP3, DIR3);

void setMaxSpeed3(float s);
void setAccel3(float a);
void setRunConfig();
void doHoming();
void homingPhase(float speed, uint32_t drainMs);
void moveAllTo(long pos);
bool readSwitch(uint8_t pin, bool &state, uint32_t &lastTime, uint32_t dMs);
bool readButton();
void xuly_Uart();

void setup() {
  Serial.begin(115200);
  delay(100);
  Serial.println("=== DELTA ROBOT - 2-PHASE HOMING ===");
  Serial1.begin(115200);
  pinMode(HOME_BTN, INPUT_PULLUP);
  pinMode(SW1, INPUT_PULLUP);
  pinMode(SW2, INPUT_PULLUP);
  pinMode(SW3, INPUT_PULLUP);
  setMaxSpeed3(HOMING_SPEED_FAST);
  setAccel3(HOMING_ACCEL);
  Serial.println("Nhấn PB1 để bắt đầu homing...");
  while (digitalRead(HOME_BTN) == HIGH) {}
  while (digitalRead(HOME_BTN) == LOW) {}
  doHoming();
}
void loop() {
  if (readButton()) {
    Serial.println("[RE-HOME] PB1 → Re-homing...");
    homeDone = false;
    doHoming();
    return;
  }
  if (homeDone) {
    xuly_Uart();
  }
  motor1.run();
  motor2.run();
  motor3.run();
}
void doHoming() {
  Serial.println("[PHA 1] Tìm home nhanh...");
  setMaxSpeed3(HOMING_SPEED_FAST);
  homingPhase(-HOMING_SPEED_FAST, 50);
  motor1.setCurrentPosition(0);
  motor2.setCurrentPosition(0);
  motor3.setCurrentPosition(0);
  Serial.println("[PHA 1] Lùi backoff cố định 500 bước...");
  moveAllTo(BACKOFF_STEPS);
  Serial.println("[PHA 2] Tìm home chậm (chính xác)...");
  setMaxSpeed3(HOMING_SPEED_SLOW);
  homingPhase(-HOMING_SPEED_SLOW, 50);
  motor1.setCurrentPosition(0);
  motor2.setCurrentPosition(0);
  motor3.setCurrentPosition(0);
  Serial.println("[HOMING] Đã xác định HOME = 0 chuẩn xác tuyệt đối.");
  // ==== Hạ robot xuống 100 xung sau khi home xong ====
  // =====================================================
  setRunConfig();
  Serial1.println("READY");
  homeDone = true;
}
void homingPhase(float speed, uint32_t drainMs) {
  bool homed1 = false, homed2 = false, homed3 = false;
  uint32_t drain1 = 0, drain2 = 0, drain3 = 0;
  if (readSwitch(SW1, sw1_state, sw1_last, DEBOUNCE_SW_MS)) {
    motor1.move(BACKOFF_STEPS / 2);
    while (motor1.distanceToGo() != 0) motor1.run();
  }
  if (readSwitch(SW2, sw2_state, sw2_last, DEBOUNCE_SW_MS)) {
    motor2.move(BACKOFF_STEPS / 2);
    while (motor2.distanceToGo() != 0) motor2.run();
  }
  if (readSwitch(SW3, sw3_state, sw3_last, DEBOUNCE_SW_MS)) {
    motor3.move(BACKOFF_STEPS / 2);
    while (motor3.distanceToGo() != 0) motor3.run();
  }
  motor1.setSpeed(speed);
  motor2.setSpeed(speed);
  motor3.setSpeed(speed);
  while (!homed1 || !homed2 || !homed3) {
    uint32_t now = millis();
    if (!homed1) {
      if (drain1 > 0) {
        if (now - drain1 >= drainMs) {
          motor1.setSpeed(0);
          homed1 = true;
          Serial.println("  Motor 1 OK (PA6)");
        } else {
          motor1.runSpeed();
        }
      } else if (readSwitch(SW1, sw1_state, sw1_last, DEBOUNCE_SW_MS)) {
        drain1 = millis();
      } else {
        motor1.runSpeed();
      }
    }
    if (!homed2) {
      if (drain2 > 0) {
        if (now - drain2 >= drainMs) {
          motor2.setSpeed(0);
          homed2 = true;
          Serial.println("  Motor 2 OK (PB0)");
        } else {
          motor2.runSpeed();
        }
      } else if (readSwitch(SW2, sw2_state, sw2_last, DEBOUNCE_SW_MS)) {
        drain2 = millis();
      } else {
        motor2.runSpeed();
      }
    }
    if (!homed3) {
      if (drain3 > 0) {
        if (now - drain3 >= drainMs) {
          motor3.setSpeed(0);
          homed3 = true;
          Serial.println("  Motor 3 OK (PA7)");
        } else {
          motor3.runSpeed();
        }
      } else if (readSwitch(SW3, sw3_state, sw3_last, DEBOUNCE_SW_MS)) {
        drain3 = millis();
      } else {
        motor3.runSpeed();
      }
    }
  }
}
bool readSwitch(uint8_t pin, bool &state, uint32_t &lastTime, uint32_t dMs) {
  bool raw = (digitalRead(pin) == LOW);
  if (raw != state) {
    state = raw;
    lastTime = millis();
  }
  if ((millis() - lastTime) >= dMs) {
    return state;
  }
  return false;
}
bool readButton() {
  static bool last_stable_state = HIGH;
  bool raw = digitalRead(HOME_BTN);

  if (raw != btn_state) {
    btn_state = raw;
    btn_last = millis();
  }

  if ((millis() - btn_last) >= DEBOUNCE_BTN_MS) {
    if (last_stable_state == HIGH && btn_state == LOW) {
      last_stable_state = btn_state;
      return true;
    }
    last_stable_state = btn_state;
  }
  return false;
}
void xuly_Uart() {
  const byte numChars = 64;
  static char receivedChars[numChars];
  static byte ndx = 0;
  while (Serial1.available() > 0) {
    char rc = Serial1.read();
    if (rc != '\n') {
      if (ndx < numChars - 1) {
        receivedChars[ndx++] = rc;
      }
    } else {
      receivedChars[ndx] = '\0';
      ndx = 0;
      if (strcmp(receivedChars, "HOME") == 0) {
        Serial.println("[UART] Nhận lệnh HOME -> Tiến hành Re-homing...");
        homeDone = false;
        doHoming();
        return;
      }
      char *p = strstr(receivedChars, "T1:");
      if (p) target_theta1 = atof(p + 3);
      p = strstr(receivedChars, "T2:");
      if (p) target_theta2 = atof(p + 3);
      p = strstr(receivedChars, "T3:");
      if (p) target_theta3 = atof(p + 3);
      motor1.moveTo((long)(target_theta2 * GOC_TO_STEP));
      motor2.moveTo((long)(target_theta1 * GOC_TO_STEP));
      motor3.moveTo((long)(target_theta3 * GOC_TO_STEP));
      Serial.print("[UART-RX] M1:");
      Serial.print(target_theta1);
      Serial.print(" | M2:");
      Serial.print(target_theta2);
      Serial.print(" | M3:");
      Serial.println(target_theta3);
    }
  }
}
void moveAllTo(long pos) {
  motor1.moveTo(pos);
  motor2.moveTo(pos);
  motor3.moveTo(pos);
  while (motor1.distanceToGo() != 0 || motor2.distanceToGo() != 0 || motor3.distanceToGo() != 0) {
    motor1.run();
    motor2.run();
    motor3.run();
  }
}
void setMaxSpeed3(float s) {
  motor1.setMaxSpeed(s);
  motor2.setMaxSpeed(s);
  motor3.setMaxSpeed(s);
}
void setAccel3(float a) {
  motor1.setAcceleration(a);
  motor2.setAcceleration(a);
  motor3.setAcceleration(a);
}
void setRunConfig() {
  setMaxSpeed3(RUN_SPEED);
  setAccel3(RUN_ACCEL);
}

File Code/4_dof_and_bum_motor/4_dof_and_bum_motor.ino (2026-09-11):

#include <AccelStepper.h>

// ===================== CẤU HÌNH CHÂN =====================
// Máy bơm
#define PUMP_IN1 PA1

// Bàn xoay - Step 17, driver kiểu PUL/DIR
#define TURN_PUL_PIN PA2   // PUL+
#define TURN_DIR_PIN PA3   // DIR+

// Step motor xoay theo độ (điều khiển vị trí tương đối)
#define STEP_PIN PA4
#define DIR_PIN  PA5

// ===================== CẤU HÌNH STEP: TRỤC "GÓC" =====================
#define STEPS_PER_REV 6400     // 1/32 vi bước: 200*32
#define STEP_MAX_SPEED 10000.0f
#define STEP_ACCEL     5000.0f

// ===================== CẤU HÌNH STEP: BÀN XOAY =====================
#define TURN_STEPS_PER_REV -800.0f   // 1/4 vi bước: 200*4
#define TURN_MAX_RPM 60.0f          // giới hạn an toàn, chỉnh theo motor/tải thực tế
// steps/giây tối đa tương ứng RPM tối đa
#define TURN_MAX_SPEED (TURN_MAX_RPM * TURN_STEPS_PER_REV / 60.0f)

AccelStepper stepMotor(AccelStepper::DRIVER, STEP_PIN, DIR_PIN);
AccelStepper turnMotor(AccelStepper::DRIVER, TURN_PUL_PIN, TURN_DIR_PIN);

// ===================== BIẾN TRẠNG THÁI =====================
bool pumpOn = false;
float turnRpm = 0.0f;

// ===================== SETUP =====================
void setup() {
  Serial.begin(115200);
  Serial1.begin(115200);

  pinMode(PUMP_IN1, OUTPUT);
  digitalWrite(PUMP_IN1, LOW);

  stepMotor.setMaxSpeed(STEP_MAX_SPEED);
  stepMotor.setAcceleration(STEP_ACCEL);

  // Bàn xoay: chạy tốc độ không đổi -> không dùng move()/acceleration,
  // chỉ cần setMaxSpeed đủ lớn để runSpeed() cho phép setSpeed() tới mức đó.
  turnMotor.setMaxSpeed(TURN_MAX_SPEED);
  turnMotor.setSpeed(0);

  Serial.println("=== READY - Nhan lenh UART tu PyCharm ===");
  Serial1.println("READY");
}

// ===================== LOOP =====================
void loop() {
  xuly_Uart();
  stepMotor.run();       // trục góc: có gia tốc, chạy tới vị trí đích
  turnMotor.runSpeed();  // bàn xoay: chạy tốc độ không đổi liên tục
}

// ===================== XỬ LÝ LỆNH UART =====================
// Định dạng lệnh (kết thúc bằng '\n'):
//   PUMP:1        -> bật bơm
//   PUMP:0        -> tắt bơm
//   TURN:12.5     -> đặt tốc độ bàn xoay = 12.5 vòng/phút (âm = quay ngược, 0 = dừng)
//   STEP:90       -> quay trục góc 90 độ (tương đối, có thể âm)
void xuly_Uart() {
  const byte numChars = 64;
  static char receivedChars[numChars];
  static byte ndx = 0;

  while (Serial1.available() > 0) {
    char rc = Serial1.read();
    if (rc != '\n') {
      if (ndx < numChars - 1) {
        receivedChars[ndx++] = rc;
      }
    } else {
      receivedChars[ndx] = '\0';
      ndx = 0;

      char *p;

      // ---- Lệnh bơm ----
      p = strstr(receivedChars, "PUMP:");
      if (p) {
        int val = atoi(p + 5);
        pumpOn = (val != 0);
        digitalWrite(PUMP_IN1, pumpOn ? HIGH : LOW);
        Serial.print("[PUMP] ");
        Serial.println(pumpOn ? "ON" : "OFF");
      }

      // ---- Lệnh bàn xoay (RPM) ----
      p = strstr(receivedChars, "TURN:");
      if (p) {
        float rpm = atof(p + 5);
        rpm = constrain(rpm, -TURN_MAX_RPM, TURN_MAX_RPM);
        turnRpm = rpm;

        float stepsPerSec = rpm * TURN_STEPS_PER_REV / 60.0f;
        turnMotor.setSpeed(stepsPerSec);

        Serial.print("[TURN] rpm=");
        Serial.print(turnRpm);
        Serial.print(" -> steps/s=");
        Serial.println(stepsPerSec);
      }

      // ---- Lệnh step (quay theo độ) ----
      p = strstr(receivedChars, "STEP:");
      if (p) {
        float deg = atof(p + 5);
        long steps = (long)(deg * STEPS_PER_REV / 360.0f);
        stepMotor.move(steps);
        Serial.print("[STEP] degree=");
        Serial.print(deg);
        Serial.print(" -> steps=");
        Serial.println(steps);
      }
    }
  }
}

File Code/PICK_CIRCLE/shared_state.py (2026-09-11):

import os
import sys
import json
import time
import subprocess

import numpy as np

try:
    import cv2
except ImportError:
    print("LỖI: chưa cài opencv-python. Chạy: pip install opencv-python")
    sys.exit(1)

try:
    from PySide6.QtCore import Qt, QThread, Signal, QTimer
    from PySide6.QtGui import QImage, QPixmap, QColor, QPalette
    from PySide6.QtWidgets import (
        QApplication, QMainWindow, QWidget, QVBoxLayout, QHBoxLayout, QPushButton,
    )
except ImportError:
    print("LỖI: chưa cài PySide6. Chạy: pip install PySide6")
    sys.exit(1)

from hardware.Uart_1 import UARTComm, DEFAULT_BAUD as ROBOT_DEFAULT_BAUD, SERIAL_AVAILABLE
from kinematics.dhnghich import inverse_kinematics
from kinematics.move_delta_4dof import DeltaMotionPlanner, TIME_MOVE_FAST
# Dof4Planner (ctx.planner_dof4): planner CHUNG cho các bài toán dof4 KHÁC
# ngoài "BÀI TOÁN ĐỘNG" - ví dụ "BÀI TOÁN BẬC 4 TĨNH" (dynamic_window.py) và
# cờ csv_apply_dof4 ở CSV. VẪN dùng move_delta_4dof.py như cũ - KHÔNG đổi.
from kinematics.move_delta_4dof import DeltaMotionPlanner as Dof4Planner
# Run4DofPlanner (ctx.planner_run4dof): planner RIÊNG, CHỈ dùng bởi tab
# "BÀI TOÁN ĐỘNG" (DynamicRun4DofWindow) - có pick_dof4()/place_dof4() tách
# rời để gắp trước - chờ khung - thả sau. Không tab nào khác được dùng cái này.
from kinematics.move_run4dof import DeltaMotionPlanner as Run4DofPlanner
# RepeatKinematicsPlanner (ctx.planner_repeat): planner RIÊNG, ĐỘC LẬP -
# CHỈ dùng bởi tab "ĐÁNH GIÁ ĐỘ LẶP LẠI" (RepeatTestWindow), từ file
# kinematics/repeat_kinematics.py. KHÔNG kế thừa / không dùng chung logic
# với DeltaMotionPlanner, Dof4Planner hay Run4DofPlanner. Không tab nào
# khác được dùng cái này.
from kinematics.repeat_kinematics import RepeatKinematicsPlanner
from hardware.Uart_2 import PneumaticComm, DEFAULT_BAUD as PNEU_DEFAULT_BAUD
from vision.Cameracircle import (
    CircleTracker,
    calculate_real_properties,
    px_to_mm_scale,
    undistort_image,
    detect_circles_hsv_optimized,
)
from vision.Camera_4dof import (
    detect_objects,
    detect_frame_holes,
    mold_bounding_region,
    is_inside_region,
    _build_red_mask,
)
if SERIAL_AVAILABLE:
    pass

BASE_DIR = os.path.dirname(os.path.abspath(__file__))
CONFIG_FILE = os.path.join(BASE_DIR, "robot_config.json")
# Script canh tâm bàn xoay (chấm cam giữa khung hình, tọa độ 0,0) - chạy như
# tiến trình riêng (subprocess), KHÔNG import trực tiếp vì nó dùng cv2.imshow
# với vòng lặp blocking riêng, không thể chạy chung luồng với Qt event loop.
MANUAL_CAMERA_CENTER_SCRIPT = os.path.join(BASE_DIR, "vision", "camera_center_dot.py")

DEFAULT_HOME = (60.0, 0.0, 330.0)
DEFAULT_Z_SAFE = 340.0
DEFAULT_JOG_XY = 5.0
DEFAULT_JOG_Z = 5.0

COORD_MODE_CIRCLE = "circle"
COORD_MODE_DOF4 = "dof4"
COORD_MODE_DYNAMIC = "dynamic"

DOF4_PLACE_POINT = (0.0, 0.0)
DOF4_TARGET_ANGLE_DEG = 90.0

# Bàn xoay: động cơ step 17 (PUL/DIR, vi bước 1/4, 800 xung/vòng), firmware
# nhận thẳng lệnh "TURN:<rpm>" (vòng/phút, có thể âm). Đây là giới hạn RPM
# tối đa dùng CHUNG cho mọi nơi trong GUI (ConnectionWindow,
# DynamicRun4DofWindow...) - PHẢI khớp với TURN_MAX_RPM bên firmware Arduino
# (Uart_2.py). Không còn khái niệm PWM 0-255 (đó là của driver L298N/DC cũ).
TURNTABLE_MAX_RPM = 65.0
DET_SCALE = 0.5

CSV_COLUMNS = ["Loại", "KT/Đường kính", "X (mm)", "Y (mm)", "Góc (°)"]
CSV_FIELDNAMES = ["type", "diameter_mm", "width_mm", "height_mm", "angle_deg", "x_mm", "y_mm"]
DYN_COLUMNS = ["Loại", "Slot", "X (mm)", "Y (mm)", "Góc (°)"]


def _fmt_size_col(item):
    if item.get("width_mm") is not None and item.get("height_mm") is not None:
        return f'{float(item["width_mm"]):.1f}x{float(item["height_mm"]):.1f}'
    d = item.get("diameter_mm")
    return f'{float(d):.2f}' if d is not None else "-"


def _fmt_angle_col(item):
    a = item.get("angle_deg")
    return f'{float(a):.1f}' if a is not None else "-"


def launch_manual_camera_center(camera_index=0):
    """
    Mở script vision/camera_center_dot.py (chấm cam giữa khung hình để canh
    tâm bàn xoay) như một TIẾN TRÌNH RIÊNG (subprocess), không chặn giao
    diện chính. Trả về đối tượng subprocess.Popen nếu mở thành công, None
    nếu lỗi (ví dụ thiếu file hoặc không khởi chạy được).

    LƯU Ý: chỉ 1 tiến trình có thể giữ camera cùng lúc - phải đảm bảo mọi
    CameraThread khác đang dùng cùng camera_index đã DỪNG hẳn trước khi gọi
    hàm này.
    """
    if not os.path.isfile(MANUAL_CAMERA_CENTER_SCRIPT):
        print(f"[MANUAL CAM] Không tìm thấy file: {MANUAL_CAMERA_CENTER_SCRIPT}")
        return None
    try:
        return subprocess.Popen(
            [sys.executable, MANUAL_CAMERA_CENTER_SCRIPT, "--index", str(camera_index)]
        )
    except Exception as e:
        print(f"[MANUAL CAM] Lỗi mở camera_center_dot.py: {e}")
        return None


# =====================================================================
# CẤU HÌNH LƯU/ĐỌC FILE JSON
# =====================================================================
def load_config():
    default_cfg = {
        "home_position": list(DEFAULT_HOME),
        "z_safe": DEFAULT_Z_SAFE,
        "jog_step_xy": DEFAULT_JOG_XY,
        "jog_step_z": DEFAULT_JOG_Z,
        "robot_port": "COM9",
        "robot_baud": ROBOT_DEFAULT_BAUD,
        "pneumatic_port": "COM3",
        "pneumatic_baud": PNEU_DEFAULT_BAUD,
        "camera_index": 0,
        "calib_file": "calibration_result.npz",
        "camera_offset_x": 0.0,
        "camera_offset_y": 0.0,
        "csv_offset_x": 0.0,
        "csv_offset_y": 0.0,
        "csv_match_tolerance": 6.0,
        "csv_match_same_color": True,
        "csv_z_pick": 340.0,
        # ĐÃ ĐỔI: "turn_pwm" (0-255, dùng cho L298N/DC cũ) -> "turn_rpm"
        # (vòng/phút, dùng cho step 17 mới). Nếu file robot_config.json cũ
        # trên máy còn key "turn_pwm", nó sẽ đơn giản bị bỏ qua (không dùng
        # tới nữa) - AppContext sẽ dùng giá trị mặc định "turn_rpm" bên dưới
        # cho tới khi người dùng lưu lại từ GUI.
        "turn_rpm": 20.0,
        "step_test_angle": 90.0,
        "coord_mode": COORD_MODE_CIRCLE,
        "csv_apply_dof4": False,
        "csv_dof4_angle": 90.0,
        "dyn_z_pick": 340.0,
        "dyn_rpm": 30.0,
        "dyn_offset_x": 0.0,
        "dyn_offset_y": 0.0,
        "repeat_ax": 10.0,
        "repeat_ay": 10.0,
        "repeat_bx": -10.0,
        "repeat_by": 10.0,
        "repeat_count": 10,
        "repeat_z_pick": 300.0,
    }
    if os.path.isfile(CONFIG_FILE):
        try:
            with open(CONFIG_FILE, "r", encoding="utf-8") as f:
                saved = json.load(f)
            default_cfg.update(saved)
        except Exception as e:
            print(f"[CONFIG] Không đọc được config cũ, dùng mặc định: {e}")
    return default_cfg
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

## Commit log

2026-05-18 feat: implement inverse kinematics module for robot control
2026-05-19 Please provide the diff or description of the changes so I can generate the commit message for you.
    [Đế dưới2.stp]
2026-05-20 Thêm script Tuning PID Matlab cho Simulink
    [Tool_1.0001.ipt, Tool_1.ipt, Tool_1.stp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]
2026-05-20 Thêm tính năng tự động vẽ đồ thị trực quan cho PID
2026-05-20 Tự động tạo file script Create_Simulink_Model.m để sinh file slx & Cập nhật tên mô hình
2026-06-03 Add new files: LINK1.ipt and update CNCD2211024-.docx with detailed project specifications
    [LINK1.ipt]
2026-06-03 refactor(home): rename sketch_may15a to homing, optimize homing routine and add backoff
2026-06-11 feat: add Draw_place trajectory controller, update STM32 firmware and settings
    Added Draw_place application for trajectory control containing kinematics, GUI, PID control, and UART communication. Updated STM32 firmware with homing and control logic. Adjusted UART settings and Z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
2026-06-11 feat: initialize Delta robot control project with kinematics, PID, trajectory generation, and GUI modules
2026-06-13 Update robot simulation models, CAD designs, STM32 code, and UART communication logic
    [Base_E.ipt, Base_E.stl, Base_E_Step.stp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]
2026-06-13 Update transmission ratio u to 3.2 in simulation and report
    - Changed belt transmission ratio u from 3.8 to 3.2 in theta_after_Ud.m
    - Updated Simulink model Delta_Robot_PID.slx and its cache files
    - Updated report document Thuyet minh.docx
2026-06-14 Update CAD designs, reorganize Delta Part files, and update report document
    [Base_E.ipt, Base_E.stl, Base_E_Step.stp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]
2026-06-19 Adjust physical dimensions, serial timeout, and STM32 motor limits
    - Inverse Kinematics: Update static plate radius (R=95.0) and dynamic plate radius (r=40)
    - UART: Reduce send timeout to 1s
    - STM32: Tune down run speed to 1000 and run acceleration to 800
2026-07-01 Refactor code, add CAD/schematics/verification data, reorganize project files
    [4_DOF.ipt, đánh giá cơ khí chính xác.xlsx]
2026-07-06 Add SP_CALIB module, calibration images, update kinematics, UART, STM32 code, and design files
    [4_DOF.0001.ipt, 4_DOF.ipt, 4_DOF_2.ipt]
2026-07-17 Update project: add PRO_GUI_DELTA ROBOT, Study_Point, calibration files, new design parts, and STM32 code changes
    [25.ipt, 30.ipt, 45.ipt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]
2026-07-25 Update project files and restructure repository
    [1.csv, 2.csv, result_000_corners.csv]
2026-08-19 Update project: add 4 DOF control, Repick module, calibration data, updated CAD parts, and STM32 firmware changes
    [1.csv, 2.csv, 25.stl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]
2026-09-05 Update project files: design parts, calibration images, and documentation
    [Robot_assembly_full.0001.iam, Robot_assembly_full.0002.iam, Robot_assembly_full.iam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]
2026-09-11 Update PICK_CIRCLE: refactor kinematics, vision, windows; reorganize calib images; update STM32 firmware
    [calibration_result.yaml, point.csv, result_000_corners.csv]
2026-09-21 UI: refactor launcher - 3 horizontal buttons, embed ConnectionWindow, equalize util buttons
2026-10-08 Update code and project files: 4DOF motor, PICK_CIRCLE improvements, calibration updates, design revisions
